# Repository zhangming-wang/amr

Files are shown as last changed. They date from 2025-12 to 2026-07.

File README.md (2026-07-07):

# AMR — 两轮差速自主导航小车

## 项目简介

本项目是一个基于 **ROS2 + ESP32** 的两轮差速后驱自主导航小车（AMR, Autonomous Mobile Robot）。系统采用 **上位机（PC）+ 下位机（ESP32）** 的分布式架构，通过 **micro-ROS** 实现上下位机之间的实时通信。

- **主控芯片**：ESP32-S3（运动控制）+ ESP32-S3-CAM（视觉采集）
- **上位机**：ROS2 Humble + Qt5 桌面控制面板
- **通信方式**：WiFi（micro-ROS）+ 串口（部分传感器）
- **建图导航**：SLAM Toolbox（建图）+ Nav2（导航）
- **视觉识别**：YOLO 目标检测

---

## 系统架构

```
┌─────────────────────────────────────────────────────────────┐
│                     上位机 (PC - Ubuntu 22.04)               │
│  ┌──────────────┐  ┌──────────────┐  ┌──────────────────┐  │
│  │ control_panel │  │ image_detect │  │ navigation/nav2  │  │
│  │  (Qt5 GUI)   │  │   (YOLO)     │  │ (slam_toolbox)   │  │
│  └──────┬───────┘  └──────┬───────┘  └────────┬─────────┘  │
│         │                 │                    │             │
│  ┌──────┴─────────────────┴────────────────────┴─────────┐  │
│  │                  ROS2 Humble 核心                       │  │
│  │  ┌──────────────────────────────────────────────────┐  │  │
│  │  │           micro-ROS-Agent (协议桥接)             │  │  │
│  │  └──────────────────────────────────────────────────┘  │  │
│  │  ┌────────────┐  ┌────────────┐  ┌─────────────────┐   │  │
│  │  │ ydlidar    │  │ serial2wifi│  │ description     │   │  │
│  │  │ (激光雷达)  │  │ (串口转WiFi)│  │ (URDF模型)      │   │  │
│  │  └────────────┘  └────────────┘  └─────────────────┘   │  │
│  └────────────────────────────────────────────────────────┘  │
└─────────────────────────────────────────────────────────────┘
                              │
                      WiFi (micro-ROS)
                              │
┌─────────────────────────────┼──────────────────────────────┐
│                     下位机 (ESP32)                          │
│  ┌──────────────────────────┴───────────────────────────┐  │
│  │        ESP32-S3-CAM (视觉模块)                        │  │
│  │  - OV2640 摄像头图像采集                               │  │
│  │  - 压缩图像发布 (CompressedImage)                      │  │
│  │  - 摄像头参数动态调节                                   │  │
│  │  - 定时拍照/连续拍照                                   │  │
│  └──────────────────────────────────────────────────────┘  │
│                                                             │
│  ┌──────────────────────────────────────────────────────┐  │
│  │        ESP32-S3 (运动控制模块)                         │  │
│  │  - cmd_vel 速度指令接收                                │  │
│  │  - 双轮差速运动学解算                                   │  │
│  │  - PID + 前馈电机控制                                  │  │
│  │  - S曲线速度规划 (Speed Plan)                          │  │
│  │  - MPU6050 IMU 姿态采集                                │  │
│  │  - YDLIDAR 激光雷达数据采集                            │  │
│  │  - 里程计/运动状态发布 (MotionStatus)                   │  │
│  └──────────────────────────────────────────────────────┘  │
│                                                             │
└─────────────────────────────────────────────────────────────┘
```

---

## 目录结构

```
amr/
├── common/                     # 公共基础库（ESP32 模块共用）
│   ├── baseNode.h              # micro-ROS 节点基类（WiFi重连/心跳/序列打印）
│   ├── baseTask.h              # FreeRTOS 任务基类（生命周期管理）
│   ├── settings.h              # 全局配置（WiFi/ROS话题/服务名/TF帧ID）
│   ├── system.h                # 系统工具（WiFi监控/设备重启）
│   ├── singleton.h             # 单例模式模板
│   └── enum.h                  # 服务命令枚举（Motion/Camera Service）
│
├── ESP32_camera/               # ESP32-S3 视觉模块（PlatformIO 项目）
│   ├── src/main.cpp            # 主程序入口
│   ├── platformio.ini          # PlatformIO 配置（esp32_wroom / esp32_s3）
│   └── lib/
│       ├── camera_control/     # 摄像头硬件控制（OV2640驱动/参数管理）
│       ├── camera_node/        # micro-ROS 相机节点
│       ├── micro_ros_platformio/ # micro-ROS PlatformIO 库 (submodule)
│       └── esp32-camera/       # ESP32 摄像头驱动库 (submodule)
│
├── ESP32_motion/               # ESP32-S3 运动控制模块（PlatformIO 项目）
│   ├── src/main.cpp            # 主程序入口
│   ├── platformio.ini          # PlatformIO 配置（esp32_wroom / esp32_s3）
│   ├── include/                # 头文件
│   │   ├── motionNodeTask.h    # micro-ROS 运动节点（cmd_vel订阅/状态发布/服务）
│   │   ├── motionControlTask.h # 运动控制任务（运动学/速度规划/PID控制）
│   │   └── sensorsControlTask.h # 传感器控制任务
│   └── lib/
│       ├── motor_control/      # 电机控制（PID+前馈/编码器/PWM）
│       ├── pid_control/        # PID 控制器
│       ├── ff_control/         # 前馈控制器
│       ├── speed_plan/         # S曲线速度规划器
│       ├── pwm_control/        # PWM 输出控制
│       ├── mpu6050_control/    # MPU6050 IMU 驱动
│       ├── lidar_control/      # YDLIDAR 激光雷达驱动
│       ├── micro_ros_platformio/ # micro-ROS PlatformIO 库 (submodule)
│       └── ESP32Encoder/       # ESP32 编码器库 (submodule)
│
├── ros2_master/                # ROS2 上位机工作空间
│   └── src/
│       ├── control/            # 控制相关功能包
│       │   ├── control_panel/  # Qt5 桌面控制面板（摄像头/运动监控/参数调节）
│       │   ├── control_launch/ # 控制启动文件
│       │   ├── image_detect/   # YOLO 图像检测
│       │   ├── camera_settings_service/ # 摄像头设置服务（.srv 定义）
│       │   ├── motion_settings_service/ # 运动设置服务（.srv 定义）
│       │   ├── motion_status_msgs/      # 运动状态消息（.msg 定义）
│       │   ├── micro-ROS-Agent/  # micro-ROS 代理 (submodule)
│       │   └── micro_ros_msgs/   # micro-ROS 消息定义 (submodule)
│       ├── lidar/              # 激光雷达功能包
│       │   ├── ydlidar/        # YDLIDAR 雷达驱动
│       │   ├── serial2wifi/    # 串口转WiFi（TCP/UDP/Serial Server）
│       │   └── lidar_launch/   # 雷达启动文件
│       ├── nav2/               # 导航功能包
│       │   ├── navigation/     # Nav2 + SLAM Toolbox 配置与启动
│       │   └── command/        # 导航指令脚本（目标点/初始化/保存地图/路径点）
│       ├── description/        # 机器人 URDF 模型与网格文件
│       └── script/             # 实用脚本（进程管理）
│
├── micro_ros/                  # micro-ROS 固件编译配置
│   └── micro_ros_setup/        # micro-ROS 编译工具 (submodule)
│
├── test/                       # 测试代码
│   └── yolo_test/              # YOLO 检测测试
│
└── doc/                        # 项目文档与图片
    ├── images/                 # 实物照片与截图
    ├── PCB/                    # 电路板设计文件
    └── model/                  # 3D 模型文件
```

---

## 硬件组成

| 模块 | 型号/规格 | 说明 |
|---|---|---|
| 主控 | ESP32-S3 DevKitC-1 | 运动控制主控 |
| 视觉 | ESP32-S3-CAM (OV2640) | 200W像素摄像头模块 |
| 电机驱动 | TB6612 / L298N | 双路直流电机驱动 |
| 电机 | JGA37-520 编码电机 | 带霍尔编码器 |
| IMU | MPU6050 | 6轴惯性测量单元 |
| 激光雷达 | YDLIDAR X2 | 360° 激光测距 |
| 电源 | 12V 锂电池 | 整车供电 |

---

## 软件架构

### 下位机（ESP32）

基于 **Arduino 框架** 使用 **PlatformIO** 开发，采用 **FreeRTOS 多任务** 架构：

| 任务 | 核心 | 优先级 | 描述 |
|---|---|---|---|
| `motion_node_task` | Core 0 | 9 | micro-ROS 通信节点（WiFi/WiFi重连/cmd_vel订阅/状态发布/服务回调） |
| `motion_control_task` | Core 1 | 12 | 运动控制（运动学解算/速度规划/PID控制/电机驱动） |
| `sensors_control_task` | Core 1 | 9 | 传感器采集（MPU6050/YDLIDAR） |
| `camera_node_task` | Core 0 | 9 | 摄像头通信节点（图像发布/参数服务） |

**核心功能**：
- **运动学模型**：两轮差速驱动，支持前进/后退/原地旋转
- **速度规划**：S曲线加减速，支持 jerk（加加速度）限制
- **电机控制**：PID + 前馈（Feed-Forward）双闭环控制
- **参数持久化**：使用 ESP32 Preferences（NVS）存储配置

### 上位机（PC）

基于 **ROS2 Humble**，核心功能包：

| 功能包 | 描述 |
|---|---|
| `control_panel` | Qt5 GUI 控制面板（实时摄像头画面/运动状态曲线/参数在线调节） |
| `image_detect` | YOLO 目标检测节点 |
| `ydlidar` | YDLIDAR 激光雷达驱动节点 |
| `serial2wifi` | 串口-TCP/UDP WiFi 透传服务器 |
| `navigation` | Nav2 导航栈 + SLAM Toolbox 在线建图 |
| `command` | 导航指令（设定目标点/初始化位姿/保存地图/路径点跟随） |
| `description` | 机器人 URDF 模型 + TF 坐标变换树 |
| `micro-ROS-Agent` | micro-ROS ↔ ROS2 协议桥接代理 |

### 通信拓扑

```
ESP32-Camera  ──WiFi(micro-ROS)──┐
ESP32-Motion  ──WiFi(micro-ROS)──┤
YDLIDAR ──串口── ESP32-Motion ───┼── micro-ROS-Agent ── ROS2 核心
```

**ROS2 话题列表**：

| 话题 | 类型 | 方向 | 说明 |
|---|---|---|---|
| `/cmd_vel` | `geometry_msgs/Twist` | PC→ESP32 | 导航速度指令 |
| `/esp32/motion_status_topic` | `motion_status_msgs/MotionStatus` | ESP32→PC | 运动状态（速度/里程/IMU/雷达） |
| `/esp32/compressed_image_topic` | `sensor_msgs/CompressedImage` | ESP32→PC | 压缩图像 |
| `/odom` | `nav_msgs/Odometry` | PC发布 | 里程计（融合后） |
| `/imu` | `sensor_msgs/Imu` | PC发布 | IMU数据 |
| `/joint_states` | `sensor_msgs/JointState` | PC发布 | 关节状态 |

**ROS2 服务列表**：

| 服务 | 说明 |
|---|---|
| `/esp32/motion_settings_service` | 运动参数/配置读写保存（PID/前馈/速度规划/电机引脚等） |
| `/esp32/camera_settings_service` | 摄像头参数读写保存 |

---

## 开发环境

| 工具/软件 | 版本/说明 |
|---|---|
| 操作系统 | Ubuntu 22.04 |
| ROS2 | Humble Hawksbill |
| Qt | 5.x（桌面控制面板） |
| IDE | VS Code + PlatformIO 插件 |
| 下位机框架 | Arduino (ESP32) + FreeRTOS |
| 3D 建模 | FreeCAD |
| 电路设计 | 嘉立创专业版 (EasyEDA Pro) |

---

## 快速开始

### 1. 克隆仓库

```bash
git clone --recurse-submodules <repo-url>
cd amr
```

### 2. 编译 micro-ROS 固件库

参见 [micro_ros/](micro_ros/) 目录下的说明，使用 micro_ros_setup 工具生成 PlatformIO 所需的静态库。

### 3. 编译并烧录 ESP32 固件

使用 VS Code 打开 `ESP32_motion/` 或 `ESP32_camera/` 目录，通过 PlatformIO 插件：

- **ESP32_motion**：选择 `esp32_wroom`（ESP32 标准版）或 `esp32_s3`（ESP32-S3）
- **ESP32_camera**：选择 `esp32_wroom` 或 `esp32_s3`（需 PSRAM）

```bash
# 或使用 PlatformIO CLI
cd ESP32_motion
pio run -e esp32_s3 --target upload
```

### 4. 编译上位机 ROS2 工作空间

```bash
cd ros2_master
colcon build
source install/setup.bash
```

### 5. 启动系统

系统提供了模块化的 launch 文件，可根据需求组合启动。启动前需确保 ESP32 设备已上电并连接 WiFi，且 `common/settings.h` 中的 WiFi 配置与路由器匹配。

#### 5.1 仅查看机器人模型（不需要下位机）

```bash
ros2 launch description description.launch.py
```

启动 `robot_state_publisher`（发布 URDF 模型）和 `rviz2`，用于离线查看机器人 3D 模型和 TF 坐标树。

#### 5.2 启动基础控制系统（遥控/图像）

```bash
ros2 launch control_launch control.launch.py
```

此命令启动以下节点：

| 节点 | 功能 |
|---|---|
| `micro_ros_agent` | micro-ROS UDP 代理（端口 8888），与 ESP32 通信 |
| `control_panel` | Qt5 桌面控制面板（实时图像/运动状态/参数调节） |
| `yolo_detect` | YOLO 目标检测（订阅摄像头图像） |
| `ekf_node` | robot_localization EKF 融合（输出 `/odom_filtered`） |
| `robot_state_publisher` | 发布 TF 坐标变换（URDF 模型） |
| `description_rviz2` | rviz2 显示机器人模型 |

#### 5.3 启动激光雷达

```bash
ros2 launch lidar_launch lidar.launch.py
```

启动 `serialserver`（串口转 WiFi 透传）、`ydlidar_node`（雷达驱动）和 `scan_to_scan_filter_chain`（激光滤波）。

> **注意**：YDLIDAR 通过串口连接 ESP32，雷达数据经 ESP32 通过 micro-ROS 上传至 PC。若雷达直连 PC 串口，需调整 `lidar_params.yaml` 中的串口配置。

#### 5.4 建图模式（SLAM）

```bash
ros2 launch navigation slam_toolbox.launch.py
```

自动启动 `control.launch.py` + `lidar.launch.py` + `slam_toolbox`（online_async 在线建图），使用游戏手柄或 `control_panel` 遥控小车移动完成环境建图。

**保存地图**：

```bash
ros2 run command save_map
```

地图默认保存至 `ros2_master/src/nav2/navigation/map/room.yaml`，保存路径可在 `save_map.py` 中修改。

#### 5.5 导航模式（Nav2）

```bash
ros2 launch navigation navigation.launch.py
```

自动启动 `control.launch.py` + `lidar.launch.py` + `nav2_bringup`（导航栈）+ `rviz2`（导航视图），并在 1 秒后自动初始化位姿。

**发送导航目标**：

```bash
# 移动到指定坐标（x, y, 角度）
ros2 run command goto_pose 1.0 0.5 0.0

# 路径点跟随
ros2 run command waypoints_follow
```

#### 5.6 一键启动全部（建图 or 导航）

```bash
# 建图
ros2 launch navigation slam_toolbox.launch.py

# 导航（需先完成建图并保存地图）
ros2 launch navigation navigation.launch.py
```

两者均已包含 `control.launch.py` 和 `lidar.launch.py`，无需单独启动。

#### 5.7 启动流程总结

```
                    ┌─────────────────────────────┐
                    │  1. ESP32 上电，连接 WiFi    │
                    └─────────────┬───────────────┘
                                  │
                    ┌─────────────▼───────────────┐
                    │  2. 启动 micro_ros_agent     │
                    │     (含于 control.launch)    │
                    └─────────────┬───────────────┘
                                  │
                    ┌─────────────▼───────────────┐
                    │  3. ESP32 自动连接 agent     │
                    │     建立 micro-ROS 通信      │
                    └─────────────┬───────────────┘
                                  │
               ┌──────────────────┼──────────────────┐
               │                  │                  │
     ┌─────────▼──────┐  ┌───────▼───────┐  ┌───────▼──────┐
     │  建图模式       │  │  导航模式      │  │  遥控模式     │
     │  slam_toolbox  │  │  navigation   │  │  control     │
     │  (遥控+建图)    │  │  (自主导航)    │  │  (手动遥控)   │
     └────────────────┘  └───────────────┘  └──────────────┘

```

## 实物展示

### 各模块
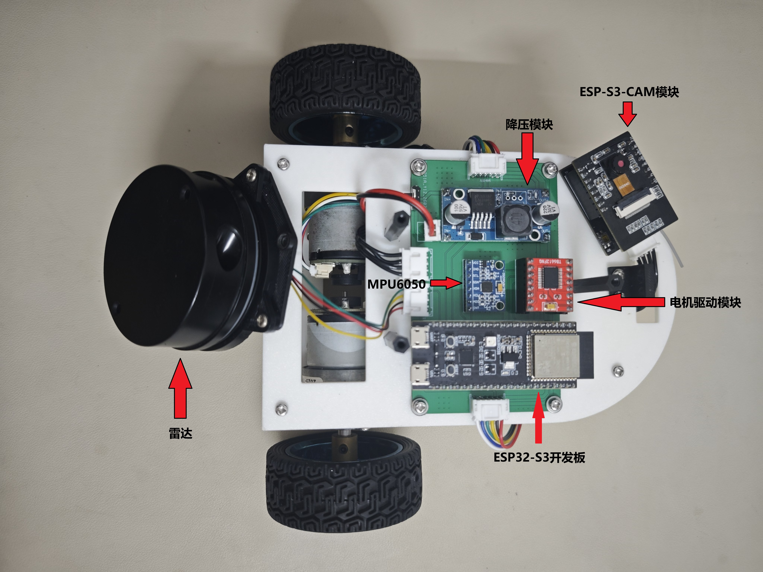
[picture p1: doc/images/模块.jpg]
模块


### 小车
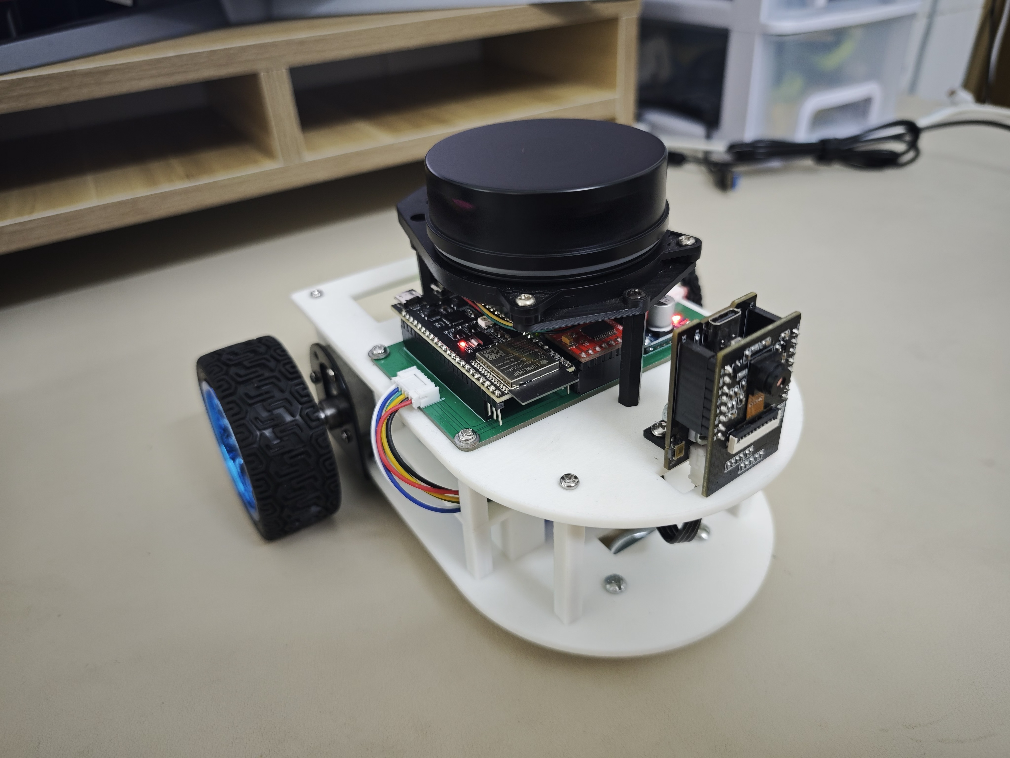
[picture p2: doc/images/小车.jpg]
小车


### 上位机软件
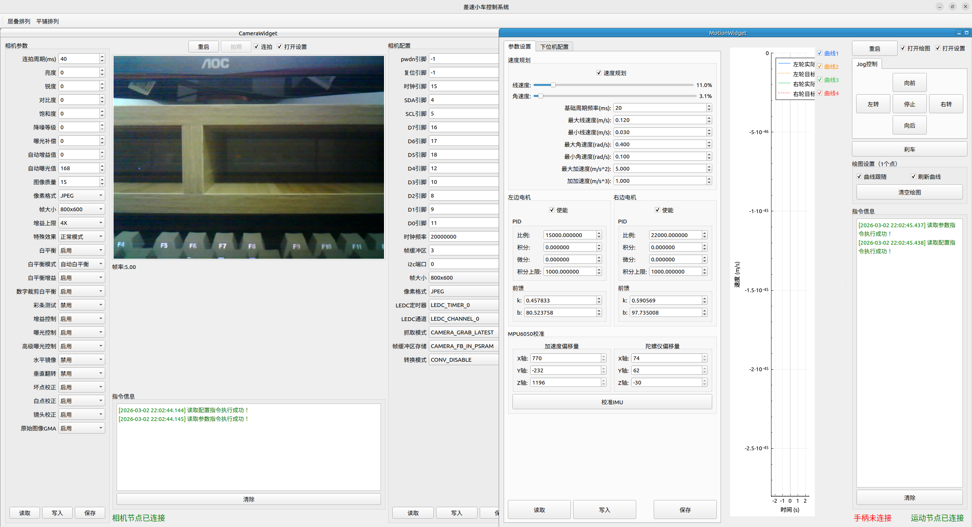
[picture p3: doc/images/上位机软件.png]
上位机


### rviz2
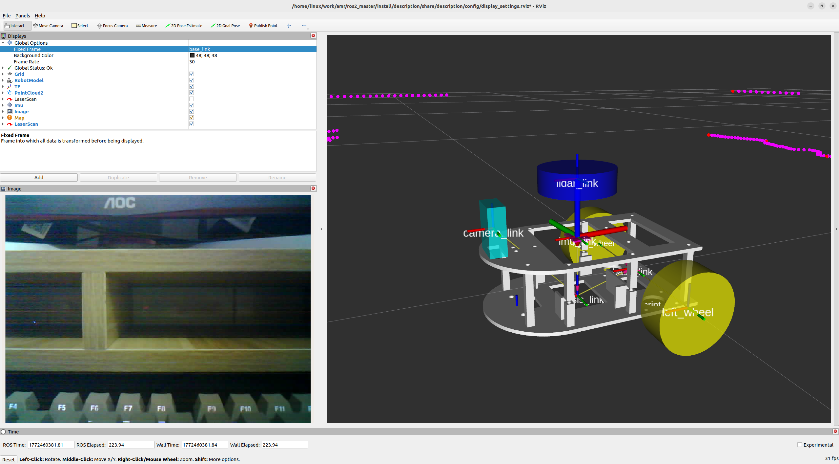
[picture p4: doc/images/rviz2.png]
rviz2


### 建图（2.5倍速播放）
建图

### 导航（2倍速播放）
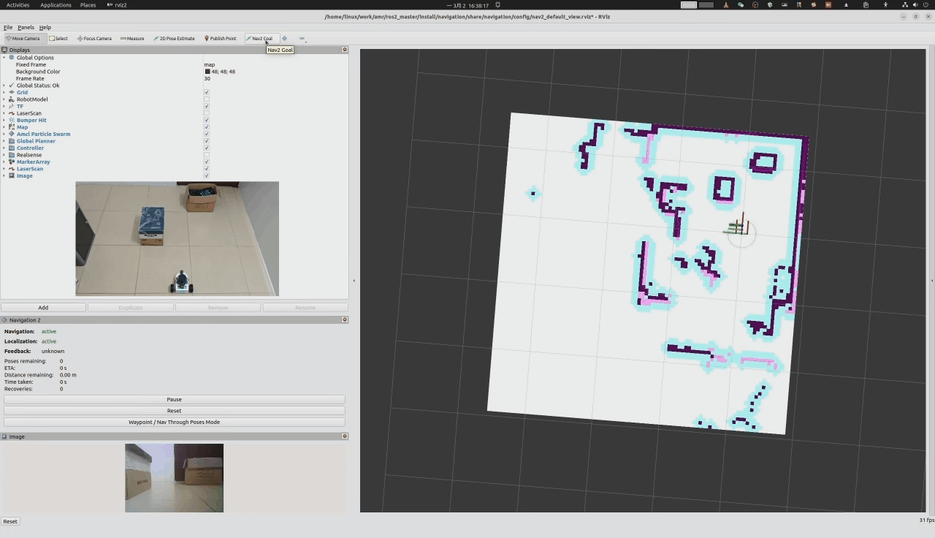
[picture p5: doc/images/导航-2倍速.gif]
导航


---

## 第三方依赖

### ESP32 固件库（submodule）
- [micro_ros_platformio](https://github.com/micro-ROS/micro_ros_platformio) — micro-ROS PlatformIO 集成
- [esp32-camera](https://github.com/espressif/esp32-camera) — ESP32 摄像头驱动
- [ESP32Encoder](https://github.com/madhephaestus/ESP32Encoder) — ESP32 编码器库

### ROS2 包（submodule）
- [micro-ROS-Agent](https://github.com/micro-ROS/micro-ROS-Agent) — micro-ROS 代理
- [micro_ros_msgs](https://github.com/micro-ROS/micro_ros_msgs) — micro-ROS 消息定义
- [micro_ros_setup](https://github.com/micro-ROS/micro_ros_setup) — micro-ROS 编译配置工具

---

## 许可证

本项目基于 [LICENSE](LICENSE) 文件中的条款发布。

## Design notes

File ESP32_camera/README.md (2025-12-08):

## 所需第三方库
    https://github.com/micro-ROS/micro_ros_platformio.git
    https://github.com/madhephaestus/ESP32Encoder.git
    https://github.com/madhephaestus/ESP32Servo.git
    https://github.com/espressif/esp32-camera.git
    https://github.com/jrowberg/i2cdevlib.git

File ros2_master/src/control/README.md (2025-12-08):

# 编译 micro-ROS-Agent 功能包

## 克隆仓库
在当前目录打开终端执行
- ```git clone -b humble https://github.com/micro-ROS/micro-ROS-Agent.git```
- ```git clone -b humble https://github.com/micro-ROS/micro_ros_msgs.git```

## 编译
- ```colcon build```
- ```source install/setup.bash```

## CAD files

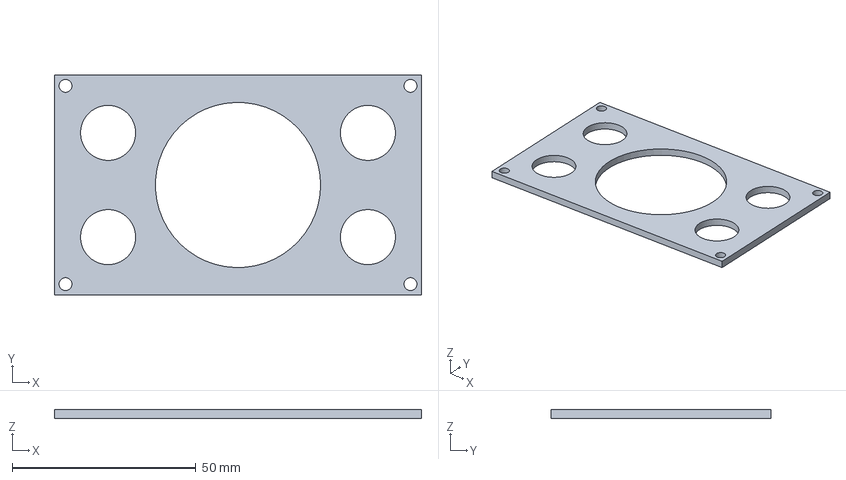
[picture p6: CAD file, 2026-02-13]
doc/model/电路板挡板.FCStd
100.0 x 60.0 x 2.50 mm

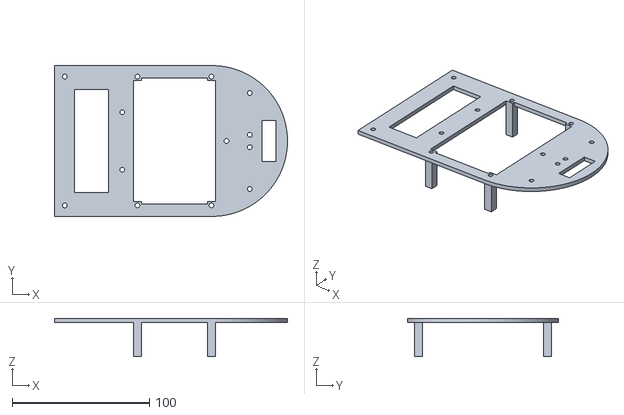
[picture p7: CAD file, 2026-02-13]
ros2_master/src/description/mesh/upper_chassis.stl
170.0 x 110.0 x 28.0

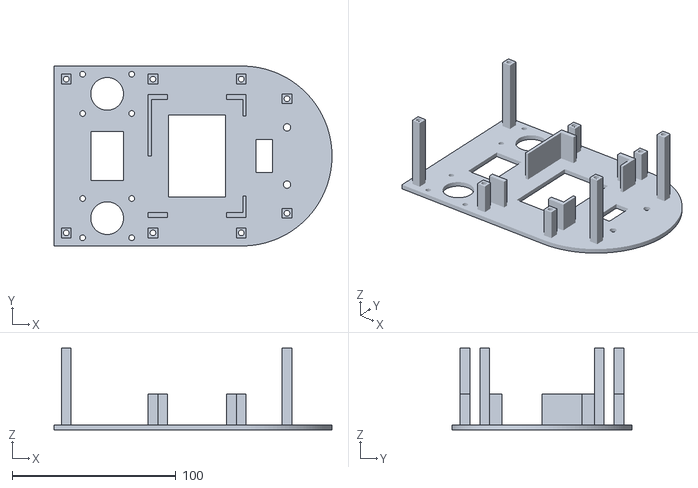
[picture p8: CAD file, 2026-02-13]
ros2_master/src/description/mesh/lower_chassis.stl
170.0 x 110.0 x 50.0

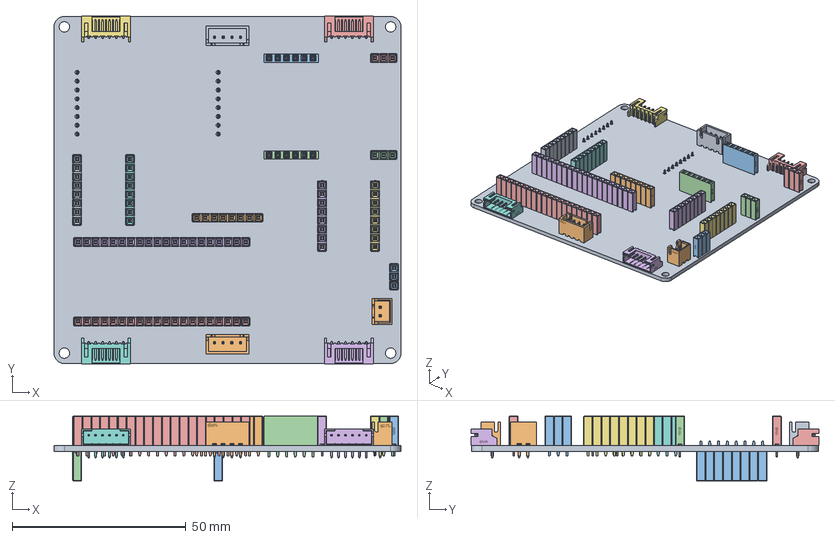
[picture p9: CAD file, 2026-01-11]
doc/model/电路板.FCStd
100.0 x 100.2 x 18.6 mm
Board~syzn
CONN-TH_2P-P2.50-XH2.54-2P~CONN-TH_2P-P2.50-XH2.54-2P~rvSB
HDR-TH_6P-P2.54-V-F~HDR-TH_6P-P2.54-V-F~4Bdj
HDR-TH_6P-P2.54-V-F~HDR-TH_6P-P2.54-V-F~4Bdj001
CONN-TH_2.0-6P-WZ-D~CONN-TH_2.0-6P-WZ-D~n98N
CONN-TH_2.0-6P-WZ-D~CONN-TH_2.0-6P-WZ-D~n98N001
CONN-TH_2.0-6P-WZ-D~CONN-TH_2.0-6P-WZ-D~n98N002
CONN-TH_2.0-6P-WZ-D~CONN-TH_2.0-6P-WZ-D~n98N003
CONN-TH_4P-P2.50_ZHOURI_XH-4PA~CONN-TH_4P-P2.50_ZHOURI_XH-4PA~oKEx
CONN-TH_4P-P2.50_ZHOURI_XH-4PA~CONN-TH_4P-P2.50_ZHOURI_XH-4PA~oKEx001
HDR-TH_3P-P2.54-V-F~HDR2.54-F-LI-1X3P~606y
HDR-TH_3P-P2.54-V-F~HDR2.54-F-LI-1X3P~606y001
HDR-TH_3P-P2.54-V-F~HDR2.54-F-LI-1X3P~606y002
HDR-TH_8P-P2.54-V-F-1~HDR-F-2.54_1x8~SxIt
HDR-TH_8P-P2.54-V-F-1~HDR-F-2.54_1x8~SxIt001
HDR-TH_8P-P2.54-V-F-1~HDR-F-2.54_1x8~SxIt002
HDR-TH_8P-P2.54-V-F-1~HDR-F-2.54_1x8~SxIt003
HDR-TH_8P-P2.54-V-F-1~HDR-F-2.54_1x8~SxIt004
HDR-TH_8P-P2.54-V-F-1~HDR-F-2.54_1x8~SxIt005
HDR-TH_8P-P2.54-V-F-1~HDR-F-2.54_1x8~SxIt006
HDR-TH_20P-P2.54-V-F~HDR-F-2.54_1x20~kLHb
HDR-TH_20P-P2.54-V-F~HDR-F-2.54_1x20~kLHb001

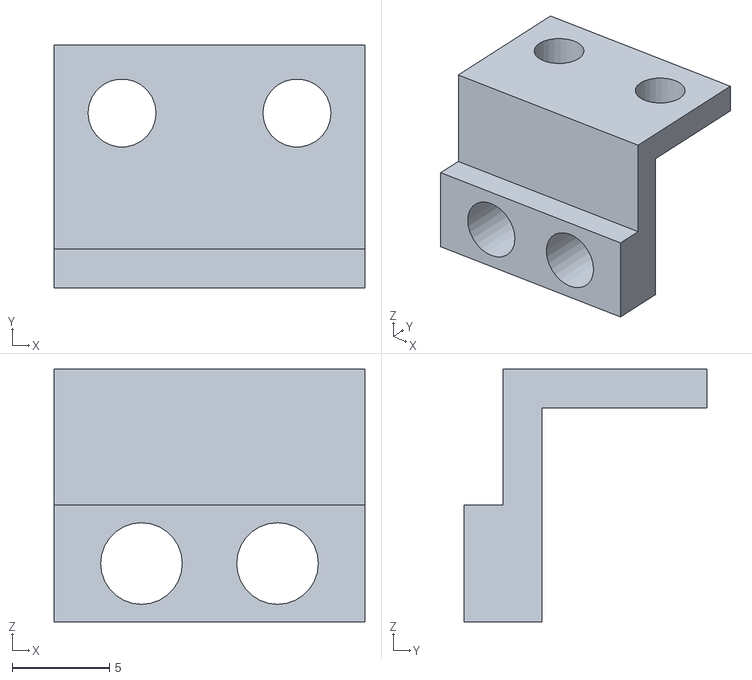
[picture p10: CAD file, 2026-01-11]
doc/model/相机支撑杆-Body.stl
16.0 x 12.5 x 13.0

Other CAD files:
doc/model/两轮上壳.FCStd
doc/model/两轮上壳-Body.stl
doc/model/两轮底壳-Body.stl
doc/model/电路板挡板-Body.stl
doc/model/两轮底壳.FCStd
doc/model/相机支撑杆.FCStd

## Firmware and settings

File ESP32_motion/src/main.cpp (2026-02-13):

#include "motionControlTask.h"
#include "motionNodeTask.h"
#include "sensorsControlTask.h"
#include "settings.h"
#include "system.h"
#include <Arduino.h>

void (*serial_print)(const std::string &) = MotionNodeTask::serial_print;

void setup() {
    Serial.begin(115200);
    delay(500);

    test_ram();

    WiFi.mode(WIFI_STA);
    WiFi.persistent(false);

    auto sensorsControlTask = &SensorsControlTask::instance();
    sensorsControlTask->start_task();

    auto motionControlTask = &MotionControlTask::instance();
    motionControlTask->start_task();

    auto motionNodeTask = &MotionNodeTask::instance();
    motionNodeTask->start_task();
}

void loop() {
    vTaskDelay(pdMS_TO_TICKS(1000));
}

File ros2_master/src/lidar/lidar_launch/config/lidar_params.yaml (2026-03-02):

ydlidar_node:
  ros__parameters:
    port: /tmp/tty_lidar # 激光雷达端口
    frame_id: lidar_link # 坐标系ID
    scan_topic_name: /scan # 扫描话题名称
    points_topic_name: /scan/points # 点云话题名称
    ignore_array: "" # 忽略的数组
    baudrate: 115200 # 波特率
    lidar_type: 1 # 激光雷达类型
    device_type: 0 # 设备类型
    sample_rate: 3 # 采样率
    intensity_bit: 8 # 强度位数
    abnormal_check_count: 4 # 异常检查计数
    fixed_resolution: false # 固定分辨率
    reversion: true # 反转
    inverted: true # 倒置
    auto_reconnect: true # 自动重连
    isSingleChannel: true # 单通道
    intensity: true # 强度
    support_motor_dtr: true # 支持电机DTR
    angle_max: 180.0 # 最大角度
    angle_min: -180.0 # 最小角度
    range_max: 6.0 # 最大范围
    range_min: 0.15 # 最小范围
    frequency: 6.0 # 频率
    invalid_range_is_inf: false # 无效范围为无穷大

tcpserver:
  ros__parameters:
    tcp_port: 8889
    serial_port: /tmp/tty_lidar

serialserver:
  ros__parameters:
    serial_port: /tmp/tty_lidar
    motion_status_topic: /esp32/motion_status_topic

scan_to_scan_filter_chain:
  ros__parameters:

    filter1:
      name: speckle_filter
      type: laser_filters/LaserScanSpeckleFilter
      params:
        filter_type: 0              # 0 = 连续邻域模式（推荐）
        max_range: 6.0              # 参与判断的最大距离
        max_range_difference: 0.2   # 邻近点差值超过 0.2m 视为噪点
        filter_window: 7            # 检查窗口大小（X2D 建议 >=7）

    filter2:
      name: median_filter
      type: laser_filters/LaserScanMedianSpatialFilter
      params:
        window_size: 3   # 中值窗口大小（不要太大，X2D 频率低）

    # filter3:
    #   name: interp
    #   type: laser_filters/InterpolationFilter
    #   params:
    #     num_points: 450   # 固定输出点数

    # 1️⃣ 角度裁剪
    # 只保留机器人前方数据，减少无用数据和后方电机干扰
    # filter1:
    #   name: angular_bounds
    #   type: laser_filters/LaserScanAngularBoundsFilter
    #   params:
    #     lower_angle: -2.0      # 最小角度（弧度），-2rad ≈ -114°
    #     upper_angle: 2.0       # 最大角度（弧度），2rad ≈ 114°

    # # 2️⃣ 距离裁剪
    # # 去掉过近和过远的无效数据
    # filter2:
    #   name: range_filter
    #   type: laser_filters/LaserScanRangeFilter
    #   params:
    #     lower_threshold: 0.12  # 小于 12cm 的数据删除（X2D 近距离误报多）
    #     upper_threshold: 6.0   # 超过 6m 删除（X2D 远距离不稳定）

    # 3️⃣ 去孤立噪点（核心滤波）
    # 处理单个或少量跳动点（X2D 常见问题）
    # filter3:
    #   name: speckle_filter
    #   type: laser_filters/LaserScanSpeckleFilter
    #   params:
    #     filter_type: 0              # 0 = 连续邻域模式（推荐）
    #     max_range: 6.0              # 参与判断的最大距离
    #     max_range_difference: 0.2   # 邻近点差值超过 0.2m 视为噪点
    #     filter_window: 7            # 检查窗口大小（X2D 建议 >=7）

    # 4️⃣ 去阴影点
    # 处理墙角和遮挡产生的虚假线条
    # filter4:
    #   name: shadow_filter
    #   type: laser_filters/ScanShadowsFilter
    #   params:
    #     min_angle: 10.0                 # 阴影判断最小角度（度）
    #     max_angle: 170.0                # 阴影判断最大角度（度）
    #     neighbors: 30                   # 参与判断的邻居数量
    #     window: 1                       # 搜索窗口
    #     remove_shadow_start_point: true # 是否移除阴影起始点

    # 5️⃣ 中值滤波（轻度平滑）
    # 让数据更平滑，但避免延迟过大
    # filter5:
    #   name: median_filter
    #   type: laser_filters/LaserScanMedianSpatialFilter
    #   params:
    #     window_size: 3   # 中值窗口大小（不要太大，X2D 频率低）

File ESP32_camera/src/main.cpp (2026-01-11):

#include "cameraControl.h"
#include "cameraNode.h"
#include "esp_timer.h"
#include "settings.h"
#include "system.h"
#include <Arduino.h>
#include <WiFi.h>

void (*serial_print)(const std::string &) = CameraNode::serial_print;

void setup() {
    Serial.begin(115200);
    while (!Serial) { // 等待主机连接到 CDC 端口
        delay(50);
    }

    test_ram();

    WiFi.mode(WIFI_STA);
    WiFi.persistent(false);
    CameraControl &cameraControl = CameraControl::instance();
    cameraControl.init_camera(true);

    CameraNode &cameraNode = CameraNode::instance();
    cameraNode.start_task();
}

void loop() {
    vTaskDelay(pdMS_TO_TICKS(1000));
}

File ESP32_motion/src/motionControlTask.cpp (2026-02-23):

#include "motionControlTask.h"

MotionControlTask::MotionControlTask() {
    task_name_ = "motion_control_task";
    priority_ = 12;
    core_id_ = 1;
    stack_size_ = 16384;

    mutex_ = xSemaphoreCreateMutex();

    task_tick_count_ = xTaskGetTickCount();

    speedPlan_ = std::make_shared<SpeedPlan>();
    left_motor_control_ = std::make_shared<MotorControl>("lm");
    right_motor_control_ = std::make_shared<MotorControl>("rm");

    _load_config();
    _load_params();

    _refresh_target_max_v();
}

void MotionControlTask::set_motor_enable_flags(uint8_t flags) {
    motor_enable_flags_ = flags;
}

uint8_t MotionControlTask::get_motor_enable_flags() {
    return motor_enable_flags_;
}

void MotionControlTask::set_speed_plan_parms(const SpdPlanParams &params) {
    auto params_copy = params;
    params_copy.max_v = fabs(params_copy.max_v);
    params_copy.max_w = fabs(params_copy.max_w);

    if (params_copy.max_v > target_max_v_)
        params_copy.max_v = target_max_v_;
    if (params_copy.max_w > target_max_w_)
        params_copy.max_w = target_max_w_;

    linear_speed_percent_ = params_copy.max_v / target_max_v_;
    angular_speed_percent_ = params_copy.max_w / target_max_w_;

    speedPlan_->set_params(params_copy);
}
const SpdPlanParams &MotionControlTask::get_speed_plan_parms() {
    return speedPlan_->get_params();
}

void MotionControlTask::set_speed_percent(float linear_percent, float angular_percent) {
    linear_percent = fabs(linear_percent);
    angular_percent = fabs(angular_percent);
    if (linear_percent >= 1)
        linear_percent = 1;
    if (angular_percent >= 1)
        angular_percent = 1;

    linear_speed_percent_ = linear_percent;
    angular_speed_percent_ = angular_percent;

    auto spd_params = speedPlan_->get_params();
    spd_params.max_v = target_max_v_ * linear_speed_percent_;
    spd_params.max_w = target_max_w_ * angular_speed_percent_;

    speedPlan_->set_params(spd_params);
}

void MotionControlTask::get_speed_percent(float &linear_percent, float &angular_percent) {
    linear_percent = linear_speed_percent_;
    angular_percent = angular_speed_percent_;
}

void MotionControlTask::brake() {
    running_ = false;
    if (xSemaphoreTake(mutex_, portMAX_DELAY) == pdTRUE) {
        if (!wheel_speed_deque_.empty()) {
            wheel_speed_deque_.clear();
        }
        xSemaphoreGive(mutex_);
    }
    left_motor_control_->brake();
    right_motor_control_->brake();
}

void MotionControlTask::stop_move() {
    geometry_msgs__msg__Twist target_twist;
    target_twist.linear.x = 0;
    target_twist.linear.y = 0;
    target_twist.linear.z = 0;
    target_twist.angular.x = 0;
    target_twist.angular.y = 0;
    target_twist.angular.z = 0;
    set_twist(target_twist);
}

void MotionControlTask::move_front() {
    geometry_msgs__msg__Twist target_twist;
    target_twist.linear.x = speedPlan_->get_params().max_v;
    target_twist.linear.y = 0;
    target_twist.linear.z = 0;
    target_twist.angular.x = 0;
    target_twist.angular.y = 0;
    target_twist.angular.z = 0;
    set_twist(target_twist);
}

void MotionControlTask::move_back() {
    geometry_msgs__msg__Twist target_twist;
    target_twist.linear.x = -speedPlan_->get_params().max_v;
    target_twist.linear.y = 0;
    target_twist.linear.z = 0;
    target_twist.angular.x = 0;
    target_twist.angular.y = 0;
    target_twist.angular.z = 0;
    set_twist(target_twist);
}

void MotionControlTask::turn_left() {
    geometry_msgs__msg__Twist target_twist;
    target_twist.linear.x = 0;
    target_twist.linear.y = 0;
    target_twist.linear.z = 0;
    target_twist.angular.x = 0;
    target_twist.angular.y = 0;
    target_twist.angular.z = speedPlan_->get_params().max_w;
    set_twist(target_twist);
}

void MotionControlTask::turn_right() {
    geometry_msgs__msg__Twist target_twist;
    target_twist.linear.x = 0;
    target_twist.linear.y = 0;
    target_twist.linear.z = 0;
    target_twist.angular.x = 0;
    target_twist.angular.y = 0;
    target_twist.angular.z = -speedPlan_->get_params().max_w;
    set_twist(target_twist);
}

void MotionControlTask::set_twist(const geometry_msgs__msg__Twist &twist) {
    _plan_wheel_speed(_inverseKinematics(twist));
}

void MotionControlTask::set_wheels_speed(const MotionControlTask::WheelSpeed &target_wheel_speed) {
    _plan_wheel_speed(target_wheel_speed);
}

void MotionControlTask::_plan_wheel_speed(const MotionControlTask::WheelSpeed &target_wheel_speed) { // MotionControlTask::WheelSpeed &target_wheel_speed
    running_ = true;
    std::deque<MotionControlTask::WheelSpeed> speed_deque;

    if (speedPlan_->get_params().enable) {
        float MIN_V_CHANGE = 0.001;
        auto changed_left_v = target_wheel_speed.left_v - target_wheel_v_.left_v;
        auto changed_right_v = target_wheel_speed.right_v - target_wheel_v_.right_v;

        if (fabs(changed_left_v) > MIN_V_CHANGE || fabs(changed_right_v) > MIN_V_CHANGE) {
            std::map<float, int> wheel_change_map;
            wheel_change_map[std::fabs(changed_left_v)] = 0;
            wheel_change_map[std::fabs(changed_right_v)] = 1;

            float planned_current_v = 0, planned_target_v = 0, changed_v = 0;
            MotionControlTask::WheelSpeed wheel_speed;

            if (wheel_change_map.rbegin()->second == 0) {
                planned_current_v = target_wheel_v_.left_v;
                planned_target_v = target_wheel_speed.left_v;
                changed_v = changed_left_v;
            } else if (wheel_change_map.rbegin()->second == 1) {
                planned_current_v = target_wheel_v_.right_v;
                planned_target_v = target_wheel_speed.right_v;
                changed_v = changed_right_v;
            }

            std::deque<float> single_wheel_speed_deque = speedPlan_->plan(planned_current_v, planned_target_v);
            for (auto value : single_wheel_speed_deque) {
                auto speed_bi = (value - planned_current_v) / changed_v;
                if (fabs(changed_left_v) < MIN_V_CHANGE) {
                    wheel_speed.left_v = target_wheel_speed.left_v;
                } else {
                    wheel_speed.left_v = speed_bi * changed_left_v + target_wheel_v_.left_v;
                }
                if (fabs(changed_right_v) < MIN_V_CHANGE) {
                    wheel_speed.right_v = target_wheel_speed.right_v;
                } else {
                    wheel_speed.right_v = speed_bi * changed_right_v + target_wheel_v_.right_v;
                }
                speed_deque.push_back(wheel_speed);
            }
        }
    } else {
        speed_deque.push_back(target_wheel_speed);
    }

    if (xSemaphoreTake(mutex_, portMAX_DELAY) == pdTRUE) {
        wheel_speed_deque_ = std::move(speed_deque);
        xSemaphoreGive(mutex_);
    }
}
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

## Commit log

2025-09-24 实现上位机和下位机参数配置以及运动控制
    [平衡车前端外壳-Body.stl, 平衡车底部外壳-Body.stl, 平衡车电路板外壳-Body.stl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]
2025-09-25 实现上位机软件和手柄以及手机软件控制小车的运动
2025-09-27 实现小车速度的正逆解以及优化软件界面
2025-09-28 优化运动学正逆解公式和优化安卓软件界面
2025-09-30 优化整体代码
2025-10-01 完善正逆解公式
2025-10-01 上位机删除is_pubing_twist变量
2025-10-10 实现相机节点发布图像以及显示
2025-10-19 实现相机参数以及配置的修改
2025-10-20 优化esp32-s3-cam模块
2025-10-21 添加pwm舵机控制
2025-10-24 优化整个框架
2025-10-26 修复bug
2025-11-29 实现esp8266-12e以及esp32与雷达通信
2025-11-30 将雷达扫描频率还原为10hz
2025-12-06 优化软件框架
2025-12-07 整合仿真代码以及优化整个框架
    [amr_description.xacro, amr_real.xacro, amr_sim.xacro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]
2025-12-08 small fix
    [nav_root.sdf, sim_world.sdf]
2025-12-10 重构架构
    [amr_description.xacro, amr_real.xacro, amr_sim.xacro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]
2025-12-13 尝试优化架构
2025-12-15 继续尝试优化架构
2025-12-16 优化esp32架构
2025-12-17 修复micro ros bug
2025-12-19 实现micro ros的架构重组
2025-12-19 优化自定义数据消息
2025-12-21 初步实现整个架构重写以及调试
    [amr_real.xacro, amr_sim.xacro]
2025-12-21 实现电机以及mpu6050的配置
2025-12-22 增加标定mpu6050功能
2025-12-22 统一雷达话题名字
    [amr_real.xacro]
2025-12-23 添加电路设计项目
2025-12-24 添加esp32-scamm三维模型
2025-12-25 添加电路设计文件
2025-12-26 重新添加电路设计文件
2025-12-29 修复测试出现的bug
    [底壳.FCStd]
2025-12-30 重新组织功能包
    [amr_description.xacro, amr_real.xacro, amr_sim.xacro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]
2025-12-30 增加yolo模型检测图像
2025-12-31 添加pyhon版本yolo检测图像
2025-12-31 修复图像识别bug
    [ESP32-CAM.FCStd, ESP32S3-CAM.FCStd, 底壳.FCStd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]
2026-01-11 修复调试出现的bug
    [amr.xacro, amr_description.xacro, amr_real.xacro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]
2026-01-28 优化整个架构
    [amr.xacro, base.xacro, camera.xacro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]
2026-02-01 将4轮模型改成两轮差速模型
2026-02-02 优化自定义消息数据结构以及删除esp8266雷达模块
2026-02-03 尝试分成3个任务,还未调试
2026-02-03 增加前馈控制器
2026-02-03 实现三个任务调试
2026-02-03 重新梳理下位机消息
2026-02-05 增加角速度设置
2026-02-05 实现esp32-s3读取雷达数据以及雷达模块数据接收正常
2026-02-13 调试各个模块
    [amr.xacro, base.xacro, camera.xacro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]
2026-02-15 调通各个模块
2026-02-23 实现建图
    [ros2_controllers.yaml]
2026-03-02 实现最终导航功能
2026-03-02 增加readMe.md
    [ESP32-CAM.FCStd, ESP32S3-CAM.FCStd, 底壳-Body.stl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]
2026-03-02 完善readMe.md
2026-03-05 修复删错settings.h中的雷达频率参数
2026-03-09 更新readme文件
2026-03-13 修复未使用融合后的odom_filtered话题
2026-04-13 修复pcb文件不对
